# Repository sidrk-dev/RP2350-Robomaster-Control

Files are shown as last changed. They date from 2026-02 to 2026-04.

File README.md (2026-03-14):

# RoboMaster Motor Control (Pico + MCP2515)

Control up to 8 DJI RoboMaster motors (M3508/M2006) using a Raspberry Pi Pico and MCP2515 CAN Bus module. This project provides a serial command interface to control position, speed, PID tuning, calibration, and homing.

## Features

- **Position Control**: Move motors to absolute angles (0-360 degrees).
- **Speed Control**: Set continuous rotation speed (RPM).
- **PID Tuning**: Adjust Angle and Speed PID gains on the fly.
- **Calibration**: Set the current physical position to a specific angle.
- **Gear Ratios**: Configure external gear reductions.
- **Multi-Motor Support**: Control up to 8 motors on a single CAN bus.
- **Brushed DC Support**: Integrated support for Cytron MD10C motor drivers.
- **Configuration Management**: GUI utility to tune PID loops, set gear ratios, and save multi-motor parameters to JSON.
- **Inverse Kinematics UI**: Full 3D 6-DOF visualization and control panel for coordinate based movement.
- **Python Control Scripts**: Control the RoboMaster and Cytron motors directly from your laptop using keyboard inputs.

## Hardware Setup

### Components
- **Microcontroller**: Raspberry Pi Pico (RP2040)
- **CAN Controller**: MCP2515 Module (SPI)
- **Motors**: DJI RoboMaster M3508 or M2006 (with C620/C610 ESCs)
- **Power Supply**: 24V DC (for motors)

### Wiring (Pico <-> MCP2515)

| Pico Pin | MCP2515 Pin | Function |
| :--- | :--- | :--- |
| GPIO 4 | SO (MISO) | SPI RX |
| GPIO 5 | CS | Chip Select |
| GPIO 6 | SCK | SPI Clock |
| GPIO 7 | SI (MOSI) | SPI TX |
| VBUS/VSYS| VCC | 5V Power |
| GND | GND | Ground |

*Note: The MCP2515 INT pin is not currently used in this code.*

> **IMPORTANT**: The Raspberry Pi Pico, MCP2515, and the Motor Controller (ESC) power supply **MUST share a common ground**. Failing to connect the grounds will result in communication failure.

### CAN Bus Wiring
- Connect generic CAN High and CAN Low from the MCP2515 to the CAN High and CAN Low on the motor ESCs.
- Ensure the CAN bus is terminated with 120Ω resistors at both ends.
- **Motor IDs**: Set motor IDs (1-8) on the ESCs according to the DJI documentation (usually by pressing the button on the ESC).

### Cytron MD10C Wiring (Optional)
If you are using a standard brushed DC motor via the Cytron MD10C:
| Pico Pin | MD10C Pin | Function |
| :--- | :--- | :--- |
| GPIO 26  | PWM | Motor Speed |
| GPIO 27  | DIR | Motor Direction |
| GND | GND | Ground |

## Software Setup

### 1. Install Arduino IDE
Download and install the latest Arduino IDE from [arduino.cc](https://www.arduino.cc/en/software).

### 2. Install Raspberry Pi Pico Board Support
1. Open Arduino IDE.
2. Go to **File** > **Preferences**.
3. In "Additional Boards Manager URLs", add:
   `https://github.com/earlephilhower/arduino-pico/releases/download/global/package_rp2040_index.json`
4. Go to **Tools** > **Board** > **Boards Manager**.
5. Search for "Pico" and install **"Raspberry Pi Pico/RP2040" by Earle F. Philhower, III**.

### 3. Libraries
All required libraries are included in the `src` folder. No manual library installation is required.

- `autowp-mcp2515` (Modified for local include)
- `RPi_Pico_TimerInterrupt` (Modified for local include)

### 4. Upload Code
1. Open `goo.ino` in Arduino IDE.
2. Connect your Raspberry Pi Pico via USB while holding the BOOTSEL button (or just connect if already in flash mode/serial enabled).
3. Select your board: **Tools** > **Board** > **Raspberry Pi Pico**.
4. Select the Port: **Tools** > **Port**.
5. Click **Upload** (Right arrow icon).

## Code Configuration (Permanent Settings)

To change default settings permanently, edit `goo.ino`:

1.  **Pin Definitions**:
    ```cpp
    #define RX_PIN 4  // gpio4 (MISO)
    #define CS_PIN 5  // gpio5 (CS)
    #define SCK_PIN 6 // gpio6 (SCK)
    #define TX_PIN 7  // gpio7 (MOSI)
    ```
2.  **Motor Count**:
    ```cpp
    #define MOTOR_NUM 8 // Change if using fewer motors
    ```
3.  **Default Gear Ratios and PID**:
    Locate the `setMotorParam()` function.
    -   Modify `motor[i].gearRatio` for M3508 (approx 19.0) or M2006 (36.0).
    -   Modify default PID values in `motor[i].anglePid` and `motor[i].speedPid`.

## Usage (Serial Monitor)

Open the **Serial Monitor** (Tools > Serial Monitor) and set the baud rate to **115200**. Ensure "Both NL & CR" or "Newline" is selected.

### Basic Commands

| Command | Description | Example |
| :--- | :--- | :--- |
| `H` | Show Help menu | `H` |
| `S` | **STOP ALL MOTORS** | `S` |

### Motor Control

| Command | Description | Example |
| :--- | :--- | :--- |
| `P <id> <angle>` | Move Motor `<id>` to limits `<angle>` (0-360) | `P 1 90` (Motor 1 to 90°) |
| `M <id> <rpm>` | Run Motor `<id>` at speed `<rpm>` | `M 2 500` (Motor 2 at 500 RPM) |
| `CAL <id> <angle>` | Calibrate: Set current position to `<angle>` | `CAL 1 0` (Set current pos as 0°) |
| `GEAR <id> <ratio>` | Set external gear ratio | `GEAR 1 5` (5:1 reduction) |
| `C <speed>` | Run Cytron motor at speed `-255` to `255` | `C 127` (50% forward) |

### PID Tuning
Adjust the control loop behavior. Values are saved until restart.

| Command | Description | Example |
| :--- | :--- | :--- |
| `AP <id> <kp> <ki> <kd>` | Set **Angle** PID | `AP 1 10.0 0.0 0.5` |
| `SP <id> <kp> <ki> <kd>` | Set **Speed** PID | `SP 1 2.0 0.1 0.0` |
| `SHOW <id>` | Show current PID values | `SHOW 1` |

## Python Control Scripts

This repository includes Python scripts and graphical interfaces to allow you to control the motors directly from your laptop.
First, make sure to install dependencies:
```bash
pip install ikpy pyserial matplotlib numpy scipy pynput
```

- **`ik_dashboard_qt.py`** (**Primary / Main arm dashboard**): Recommended day-to-day control UI for IK + runtime operation (reconnect handling, verify flow, execute/live controls).
- **`pid_tuner.py`** (**Primary tuning tool**): Dedicated Tkinter GUI for motor parameter maintenance (PID, limits, ENCMAP/ABSPID, and config persistence).
- **`ik_arm_control.py`**: Backend + legacy visualizer internals used by the Qt dashboard.
- **`keyboard_control.py`**: Hold `W` to spin RoboMaster Motor 1 forward, `S` to spin backward. `Q` to quit.
- **`differential_wrist_control.py`**: Uses WASD to control a differential wrist attached to Motors 1 and 2. `W/S` for Pitch, `A/D` for Roll.
- **`cytron_control.py`**: Hold `U` to spin the Cytron motor forward (PWM 255), `J` to spin backward. `Q` to quit.
- **`multi_motor_keyboard_control.py`**: Multi-controller keyboard velocity tool that reads controller ports from `robot_config.json`, opens all configured COM ports, and routes per-motor `M <id> <rpm>` commands with remappable keys.

## Multi-Motor Keyboard Controller (`multi_motor_keyboard_control.py`)

### Purpose
- Connects to all controller ports defined under `controllers` in `robot_config.json`.
- Routes velocity commands to the correct board based on motor assignment.
- Lets you hold/release remappable keys to command motor RPM live.

### Run
```bash
python multi_motor_keyboard_control.py
```

Optional arguments:
```bash
python multi_motor_keyboard_control.py --config robot_config.json --keymap multi_motor_keymap.json --baud 115200
```

### On startup
- If keymap file does not exist, the script creates `multi_motor_keymap.json` with defaults.
- It verifies every configured controller port is present before opening.
- It prints full usage instructions and all runtime key bindings.

### Key behavior
- Press/hold mapped **forward** key -> sends positive RPM for that motor.
- Press/hold mapped **reverse** key -> sends negative RPM for that motor.
- Release key -> sends `M <id> 0` for that motor.
- **Stop-All** key sends `S` to all connected controllers.
- **Quit** key exits and sends stop before closing ports.

### Remapping keys
Edit `multi_motor_keymap.json` and restart the script.

Schema:
```json
{
  "quit": "esc",
  "stop_all": "space",
  "blink": "b",
  "motors": {
    "1": { "forward": "1", "reverse": "q", "speed": 50 },
    "2": { "forward": "2", "reverse": "w", "speed": 50 }
  }
}
```

## Recommended Daily Workflow (Important)

This project has a multi-controller serial architecture (`base`, `joint4`, `wrist`).
Most runtime issues are from startup order, stale telemetry, or encoder mapping/offset mistakes.

### 1) One app at a time
- Do **not** run `ik_dashboard_qt.py` and `pid_tuner.py` at the same time.
- Close one before connecting with the other, or USB ports will conflict.

### 2) Power and cable checks first
- Make sure all expected controller boards are powered and plugged in.
- If one board is unplugged, motion may remain blocked in IK for safety.

### 3) Apply settings before motion
- In PID Tuner, use **Apply ALL Settings to Arm** after loading/checking config.
- In IK Dashboard, after reconnect, click **Post-Reconnect Verify + Arm Motion** before Execute/Live.

### 4) Wait for telemetry
- Confirm live `POS` telemetry appears for joints before testing motion.
- If telemetry is stale/missing, IK motion will be blocked.

---

## IK Dashboard (`ik_dashboard_qt.py`) - How to Use

### Startup
1. Launch `python ik_dashboard_qt.py`
2. Click **Connect**.
3. Wait for connection + telemetry status to become healthy.
4. Click **Post-Reconnect Verify + Arm Motion**.
5. Use **Execute** for one-shot movement or **Live Update** for continuous updates.

### Safety/Behavior Notes
- The dashboard intentionally enforces runtime safety gates:
  - runtime apply must be confirmed,
  - required controllers must be online,
  - telemetry must be live,
  - motion must be armed after verify.
- If any of the above fails, Execute is blocked and a reason is logged.

### Joint 4 note
- If Joint 4 does not move from IK, check whether backend is in planar-lock mode.
- In planar mode, joint 4 can be intentionally locked out from IK command generation.

---

## PID Tuner (`pid_tuner.py`) - How to Use

### Typical sequence
1. Launch `python pid_tuner.py`
2. Connect to controllers.
3. Review motor config values loaded from `robot_config.json`.
4. Click **Apply Encoder Mappings** (or **Apply ALL Settings to Arm**).
5. Wait briefly for encoder detection settle.
6. Apply/enable ABS PID.
7. Test with small moves first (`P`/Jog), then larger movements.

### Encoder mapping and ABSPID sequencing quirk
- ABSPID enable can fail if sent too quickly after mapping.
- Correct order is:
  1. `ENCMAP`
  2. short wait for firmware detection
  3. `ABSPID`
- The tooling now retries ABSPID enables, but you should still wait for telemetry stability.

### Shared encoder index across boards
- Same encoder index value can be reused on different controller boards.
- Conflict only matters **within the same controller** (same board/firmware instance).

---

## Common Errors and Fixes

### 1) "Motion blocked" in IK Dashboard
**Symptoms**
- Execute does nothing
- Logs mention runtime apply/telemetry/controller health

**Fix**
1. Reconnect all boards.
2. Confirm telemetry is updating.
3. Run **Post-Reconnect Verify + Arm Motion**.
4. Retry Execute.

### 2) One controller unplugged / wrong COM port
**Symptoms**
- One joint group (often J4 or wrist) never responds.
- Status shows offline/missing controller.

**Fix**
1. Check USB cable and power for that board.
2. Confirm controller mapping in `robot_config.json` (`controllers.base/joint4/wrist.port`).
3. Reconnect app and verify again.

### 3) ABSPID skipped / not enabled
**Symptoms**
- Serial log includes `ABSPID skipped`.
- Motor stays on internal encoder PID source.

**Likely causes**
- No encoder mapped for that motor.
- Encoder not detected yet right after remap.

**Fix**
1. Set correct `abs_encoder_index` for that motor.
2. Apply encoder mappings.
3. Wait ~0.2-0.5s.
4. Enable ABSPID again (or use Apply ALL).

### 4) Motor moves opposite direction
**Symptoms**
- Position correction runs away or moves opposite expected command.

**Fix**
1. Flip `abs_encoder_reversed` for that motor.
2. Re-apply encoder mapping/direction.
3. Re-enable ABSPID and retest with tiny move.

### 5) Wrong zero / bad encoder offset
**Symptoms**
- Displayed pose is offset from real arm.
- Commanded target goes to unexpected physical angle.

**Fix**
1. Put arm in known reference pose.
2. Recalibrate with `CAL <id> <angle>` (or dashboard zero capture workflow).
3. Verify `abs_zero_offset` / `ik_zero_offset` in `robot_config.json` are correct.
4. Apply settings, then sync from telemetry before executing motion.

### 6) Jog spins continuously instead of stepping
**Symptoms**
- Jog behaves like continuous speed command.

**Fix**
- Use updated PID tuner jog path that sends bounded position targets (`P`) from current telemetry reference.
- Ensure live telemetry is present before jogging.

---

## Quick Command Reference (Firmware)

- `S` -> stop all motors
- `TON` / `TOFF` -> telemetry on/off
- `P <id> <angle>` -> absolute logical position target
- `PR <id> <delta>` -> relative logical position step
- `M <id> <rpm>` -> continuous speed command
- `ENCMAP <enc_idx> <motor_id|0>` -> map/unmap absolute encoder
- `ENCREVSET <enc_idx> <0|1> <motor_id>` -> deterministic encoder direction
- `ABSPID <id> <0|1>` -> toggle absolute-encoder PID source
- `CAL <id> <angle>` -> set logical zero reference at current physical position

## Documentation

For more detailed guides, see the included markdown files:
- [PID Tuning Guide](PID_TUNING_GUIDE.md)
- [Gear Ratio Guide](GEAR_RATIO_GUIDE.md)
- [Multi-Motor Reference](MULTI_MOTOR_REFERENCE.md)

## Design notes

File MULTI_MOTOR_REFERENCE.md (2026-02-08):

# Multi-Motor Control - Quick Reference

## All Motors Now Support Position Control!

All 8 motors now have the same PID tuning and can be controlled independently for position or speed.

## Command Format Changes

### Position Control
**Old (Motor 1 only):**
```
P 90
```

**New (All motors):**
```
P 1 90      # Motor 1 to 90 degrees
P 2 180     # Motor 2 to 180 degrees
P 3 270     # Motor 3 to 270 degrees
```

### Calibration
**Old (Motor 1 only):**
```
CAL 0
```

**New (All motors):**
```
CAL 1 0     # Set Motor 1 current position to 0°
CAL 2 90    # Set Motor 2 current position to 90°
CAL 3 180   # Set Motor 3 current position to 180°
```

### PID Tuning
**Old (Motor 1 only):**
```
AP 5 1.0 0.0
SP 0.3 0 0
SHOW
```

**New (All motors):**
```
AP 1 5 1.0 0.0    # Set Motor 1 angle PID
AP 2 5 1.0 0.0    # Set Motor 2 angle PID
SP 1 0.3 0 0      # Set Motor 1 speed PID
SP 2 0.3 0 0      # Set Motor 2 speed PID
SHOW 1            # Show Motor 1 PID values
SHOW 2            # Show Motor 2 PID values
```

### Speed Control (unchanged)
```
M 1 500     # Motor 1 at 500 RPM
M 2 -300    # Motor 2 at -300 RPM
```

## Complete Command List

| Command | Format | Example | Description |
|---|---|---|---|
| **P** | `P <id> <angle>` | `P 1 90` | Move motor to absolute angle (0-360°) |
| **M** | `M <id> <speed>` | `M 2 500` | Set motor to continuous speed (RPM) |
| **CAL** | `CAL <id> <angle>` | `CAL 1 0` | Calibrate current position to angle |
| **AP** | `AP <id> <kp> <ki> <kd>` | `AP 1 5 1 0` | Set angle PID for motor |
| **SP** | `SP <id> <kp> <ki> <kd>` | `SP 1 0.3 0 0` | Set speed PID for motor |
| **SHOW** | `SHOW <id>` | `SHOW 1` | Display PID values for motor |
| **S** | `S` | `S` | Stop ALL motors |
| **H** | `H` | `H` | Show help |

## Default PID Values (All Motors)

```
Angle PID: Kp=5.0, Ki=1.0, Kd=0.0, OutLimit=500 RPM, IntLimit=5.0
Speed PID: Kp=0.3, Ki=0.0, Kd=0.0, OutLimit=20 A, IntLimit=5.0
```

These are tuned for M3508 motors (19:1 gear ratio).

## Status Display

The serial monitor now shows status for ALL motors in position control mode:

```
M1 POS:90.2 Tot:90.2 RPM:0.5 A:0.12 | M3 POS:180.1 Tot:180.1 RPM:-1.2 A:0.08 |
```

- **POS** - Current position (0-360°)
- **Tot** - Total angle (can exceed 360°)
- **RPM** - Current speed
- **A** - Current in Amps

## Example Multi-Motor Workflow

### Setup Multiple Motors
```
S                   # Stop all
CAL 1 0             # Calibrate motor 1 to 0°
CAL 2 0             # Calibrate motor 2 to 0°
CAL 3 0             # Calibrate motor 3 to 0°
```

### Coordinated Movement
```
P 1 90              # Motor 1 to 90°
P 2 180             # Motor 2 to 180°
P 3 270             # Motor 3 to 270°
```

### Individual Tuning
```
SHOW 1              # Check Motor 1 PID
AP 1 7 1 0.1        # Increase Motor 1 responsiveness
SHOW 2              # Check Motor 2 PID
AP 2 3 0.5 0.2      # Make Motor 2 more damped
```

### Return to Zero
```
P 1 0
P 2 0
P 3 0
```

## LED Indicator

The built-in LED turns ON when **any** motor is in position control mode.

## Notes

- All motors share the same default PID values at startup
- You can tune each motor independently during runtime
- PID values reset to defaults on power cycle
- Position tracking works across multiple rotations
- Shortest path is automatically calculated for position commands

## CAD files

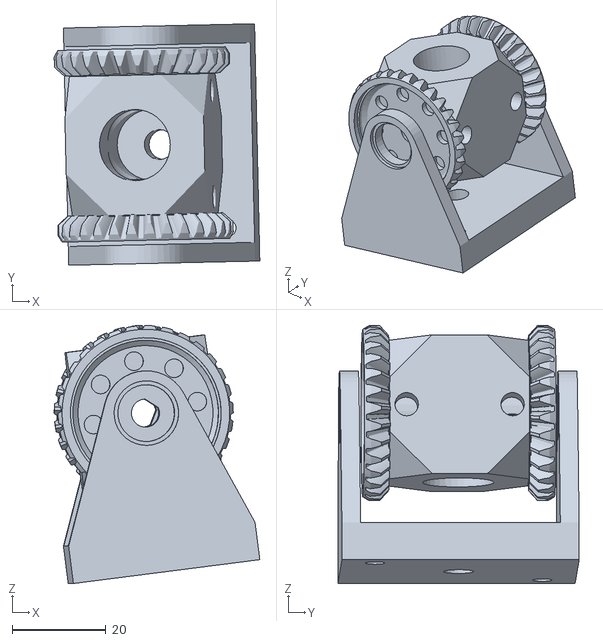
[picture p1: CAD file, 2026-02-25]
URDF/meshes/J5to6_v111.stl
43.8 x 51.4 x 54.9

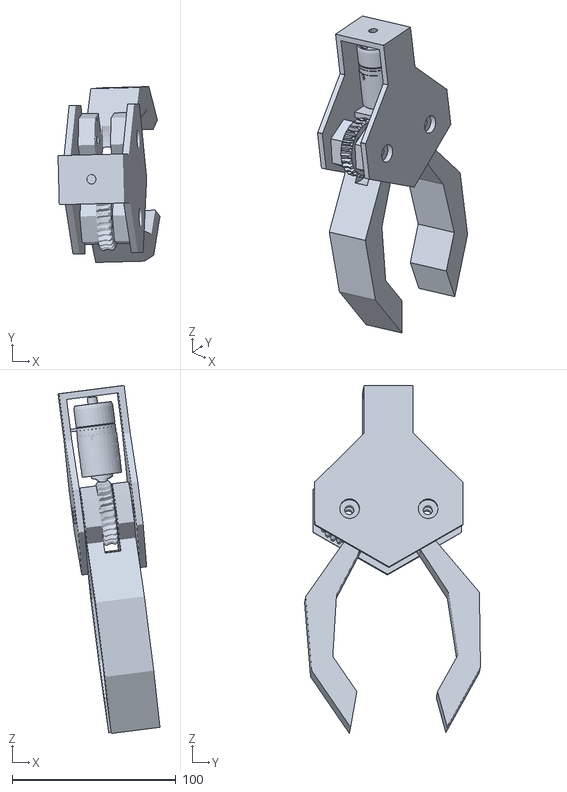
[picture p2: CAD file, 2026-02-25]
URDF/meshes/hand_v111.stl
62.3 x 107.5 x 212.7

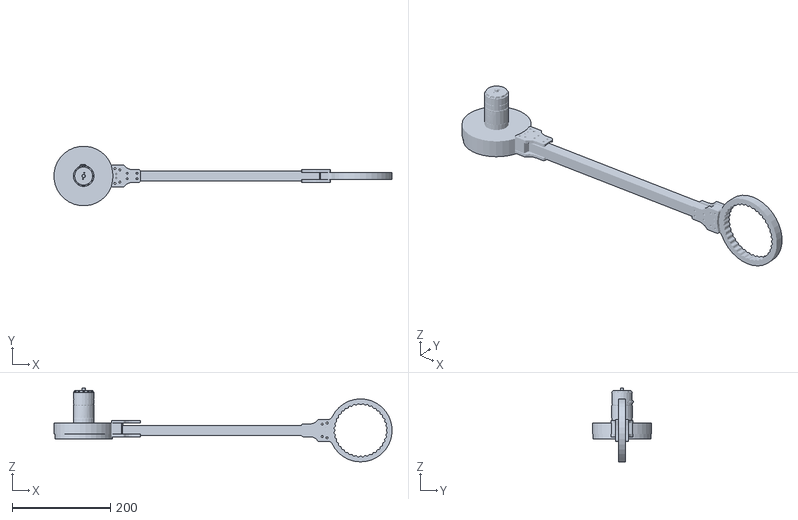
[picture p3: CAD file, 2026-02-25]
URDF/meshes/J3to4_v111.stl
686.4 x 120.7 x 149.8

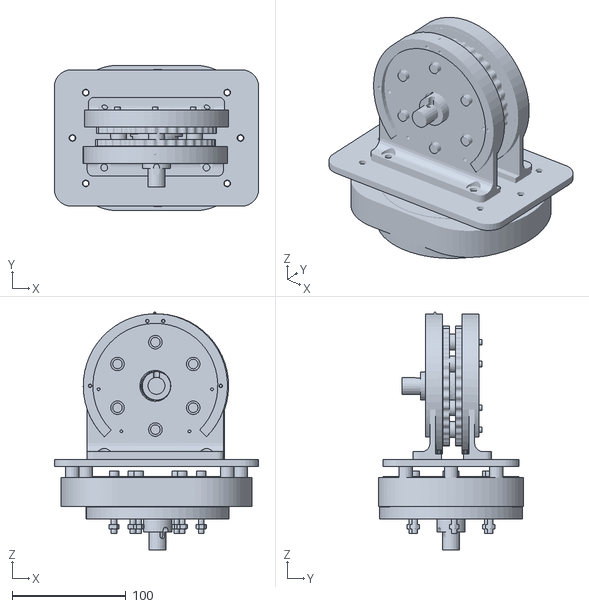
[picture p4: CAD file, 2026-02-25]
URDF/meshes/J1to2_v111.stl
180.0 x 128.0 x 209.5

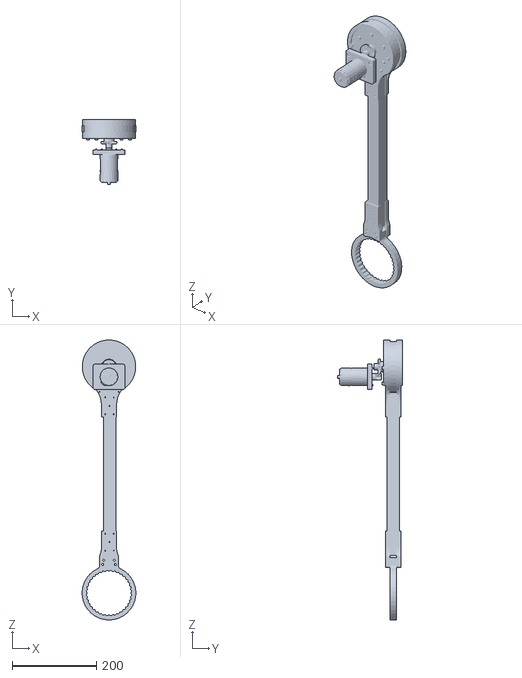
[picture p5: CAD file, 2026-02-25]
URDF/meshes/J2to3_v211.stl
127.8 x 155.1 x 665.5

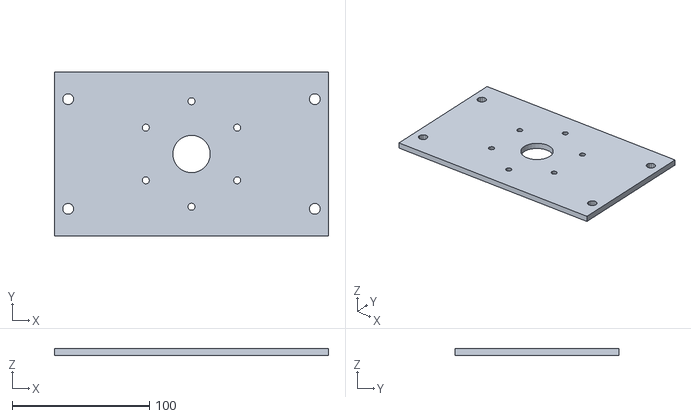
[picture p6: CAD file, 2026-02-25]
URDF/meshes/base_link.stl
200.0 x 120.0 x 5.00

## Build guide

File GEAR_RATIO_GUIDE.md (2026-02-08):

# External Gear Ratio & Calibration Fix

## What Changed

### 1. External Gear Ratio Support
Each motor can now have an **external gear ratio** in addition to its internal motor gear ratio. This is useful when you have:
- Belt/pulley reductions
- Additional gearboxes
- Chain drives
- Any external mechanical advantage

### 2. Calibration Fix
The calibration was failing because `externalGearRatio` wasn't initialized. It's now properly set to `1.0` (no external gearing) by default.

## New Command: GEAR

### Format
```
GEAR <id> <ratio>
```

### Examples
```
GEAR 1 5        # Motor 1 has 5:1 external gearing
GEAR 2 3.5      # Motor 2 has 3.5:1 external gearing
GEAR 3 1        # Motor 3 has no external gearing (default)
```

### How It Works

**Total Gear Ratio = Motor Internal Ratio × External Ratio**

For example:
- M3508 motor: 19:1 internal ratio
- External gearing: 5:1
- **Total ratio: 19 × 5 = 95:1**

This means:
- Position control works on the **final output shaft**
- Speed (RPM) is measured at the **final output**
- All calculations account for the total reduction

## Updated Workflow

### Setup with External Gearing

```bash
# 1. Set external gear ratios (if any)
GEAR 1 5        # Motor 1 has 5:1 external reduction
GEAR 2 5        # Motor 2 has 5:1 external reduction
GEAR 3 1        # Motor 3 has no external gearing

# 2. Calibrate positions
CAL 1 0         # Set Motor 1 current position to 0°
CAL 2 0         # Set Motor 2 current position to 0°
CAL 3 0         # Set Motor 3 current position to 0°

# 3. Move to positions (final output shaft degrees)
P 1 90          # Motor 1 final output to 90°
P 2 180         # Motor 2 final output to 180°
P 3 270         # Motor 3 final output to 270°
```

## Understanding the Gear Ratios

### Default Configuration (from your code)
```cpp
#define M2006_GEAR_RATIO 19.0 * 5  // = 95:1
```

This sets the **motor internal ratio** to 95:1. If you have additional external gearing, use the `GEAR` command to add it.

### Example Calculation

**Motor 1 with M3508 (19:1) + 5:1 external gearing:**

```bash
# Motor setup
motor[0].gearRatio = 95.0          # From M2006_GEAR_RATIO define
motor[0].externalGearRatio = 5.0   # Set via GEAR 1 5

# Total ratio
Total = 95.0 × 5.0 = 475:1

# If motor rotor spins 475 revolutions
# Final output shaft spins 1 revolution (360°)
```

## Calibration Now Works!

### Why It Was Broken
The `externalGearRatio` field wasn't initialized, so it had a random value (could be 0 or garbage). This caused:
- Division by zero errors
- Incorrect position calculations
- Calibration being immediately overwritten

### The Fix
```cpp
motor[i].externalGearRatio = 1.0;  // Default: no external gearing
```

Now calibration works correctly:
```bash
CAL 1 0      # Sets current position to 0°
P 1 90       # Moves to 90° (works!)
```

## Checking Your Setup

### View Total Gear Ratio
```bash
GEAR 1 5
# Output: Motor 1 external gear ratio set to 5:1 (Total ratio: 475:1)
```

### View PID Settings
```bash
SHOW 1
# Shows all PID values and limits
```

## Important Notes

### 1. Set Gear Ratio BEFORE Calibration
```bash
# CORRECT ORDER:
GEAR 1 5        # Set gear ratio first
CAL 1 0         # Then calibrate

# WRONG ORDER:
CAL 1 0         # Calibrate first
GEAR 1 5        # Changing ratio invalidates calibration!
```

### 2. Gear Ratio Affects Speed
If you set `GEAR 1 5`, the reported RPM will be 5× slower (final output speed).

### 3. Gear Ratio Affects Position
With higher gear ratios, you get:
- **More precision** (smaller motor movements = smaller output movements)
- **More torque** at the output
- **Slower maximum speed** at the output

## PID Tuning with External Gearing

Higher gear ratios may require different PID values:

```bash
# With 5:1 external gearing, you might need:
AP 1 10 1 0.2    # Higher Kp for faster response
SP 1 0.5 0 0     # Higher speed Kp
```

The position error is in **output shaft degrees**, which are smaller movements with high gear ratios.

## Complete Example Session

```bash
# Setup
H                # Show help
S                # Stop all motors

# Configure gear ratios
GEAR 1 5         # Motor 1: 5:1 external
GEAR 2 5         # Motor 2: 5:1 external  
GEAR 3 1         # Motor 3: no external gearing

# Calibrate
CAL 1 0          # Motor 1 at 0°
CAL 2 0          # Motor 2 at 0°
CAL 3 0          # Motor 3 at 0°

# Test movement
P 1 90           # Motor 1 to 90°
P 2 180          # Motor 2 to 180°
P 3 270          # Motor 3 to 270°

# Check status (shows final output positions)
# M1 POS:90.1 Tot:90.1 RPM:0.2 A:0.05 | M2 POS:180.0 ...

# Return home
P 1 0
P 2 0
P 3 0
```

## Troubleshooting

### Calibration Still Not Working?
1. Check that you set `GEAR` before `CAL`
2. Verify gear ratio is positive: `GEAR 1 5` (not 0 or negative)
3. Make sure motor is stopped before calibrating: `S` then `CAL 1 0`

### Position Drifts After Calibration?
- This is normal if the motor is moving
- Calibration sets the position at that instant
- Movement continues from the new reference

### Wrong Speed/Position Readings?
- Check your `M2006_GEAR_RATIO` define
- Verify external gear ratio is correct
- Total ratio = internal × external

## Summary

✅ **External gear ratios** now supported via `GEAR` command  
✅ **Calibration fixed** by initializing `externalGearRatio = 1.0`  
✅ **All calculations** use total gear ratio (internal × external)  
✅ **Position and speed** measured at final output shaft  

The lint errors are just IDE warnings - the code will compile fine in Arduino IDE!

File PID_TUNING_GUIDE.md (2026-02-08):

# PID Tuning Guide for RoboMaster Motor Position Control

## Overview
Your system uses **cascade PID control**:
- **Outer Loop (Position)**: Angle PID converts position error (degrees) → target speed (RPM)
- **Inner Loop (Speed)**: Speed PID converts speed error (RPM) → motor current (Amps)

## Current Problem: Motor Vibrating
This typically means the system is **over-responsive** or **oscillating**. Common causes:
1. **Kp too high** - System reacts too aggressively
2. **Kd too low** - Not enough damping
3. **Ki causing windup** - Integral term accumulating too much

## Quick Fix Commands

### View Current Settings
```
SHOW
```

### Emergency Stop
```
S
```

### Test Position Control
```
P 90
```

## Step-by-Step Tuning Process

### Phase 1: Stabilize Speed Loop First
The speed loop must be stable before tuning position control.

**Start with conservative values:**
```
SP 0.5 0 0
```

**Test with direct speed command:**
```
M 1 100
```

**Gradually increase Kp until you get good tracking:**
```
SP 1.0 0 0
SP 2.0 0 0
SP 3.0 0 0
```

**Signs of good speed control:**
- Motor reaches target RPM smoothly
- No oscillation or vibration
- Steady-state error is acceptable

**If oscillating:** Lower Kp
```
SP 0.5 0 0
```

**If sluggish:** Add a tiny bit of Ki (start very small!)
```
SP 2.0 0.1 0
```

**If noisy/jittery:** Add Kd for damping
```
SP 2.0 0.1 0.05
```

### Phase 2: Tune Position Loop
Once speed control is stable, tune the position loop.

**Start with very low Kp:**
```
AP 0.1 0 0
```

**Test position control:**
```
P 90
```

**Gradually increase Kp:**
```
AP 0.3 0 0
AP 0.5 0 0
AP 1.0 0 0
```

**Signs of good position control:**
- Motor moves smoothly to target
- Settles without overshoot
- No vibration at target position

**If vibrating at target:** Add Kd for damping
```
AP 0.5 0 0.2
AP 0.5 0 0.5
```

**If slow to reach target:** Increase Kp
```
AP 1.5 0 0.5
```

**If steady-state error (doesn't quite reach target):** Add tiny Ki
```
AP 1.0 0.05 0.5
```

## Recommended Starting Values

### For M2006 Motors (36:1 gear ratio)
```
SP 1.0 0.1 0      # Speed PID
AP 0.5 0 0.3      # Angle PID
```

### For M3508 Motors (19:1 gear ratio)
```
SP 2.0 0.2 0      # Speed PID
AP 1.0 0 0.5      # Angle PID
```

## Understanding the Parameters

### Kp (Proportional Gain)
- **What it does:** Immediate response to error
- **Too high:** Oscillation, vibration, overshoot
- **Too low:** Slow response, large steady-state error
- **Typical range:** 0.1 - 5.0

### Ki (Integral Gain)
- **What it does:** Eliminates steady-state error over time
- **Too high:** Overshoot, slow settling, instability
- **Too low:** Persistent steady-state error
- **Typical range:** 0 - 0.5 (start with 0!)
- **⚠️ Warning:** Can cause windup - use sparingly

### Kd (Derivative Gain)
- **What it does:** Damping, resists rapid changes
- **Too high:** Amplifies noise, jittery motion
- **Too low:** Overshoot, oscillation
- **Typical range:** 0 - 1.0

## Troubleshooting Guide

### Problem: Motor vibrates/oscillates at target position
**Cause:** Position loop Kp too high or Kd too low
**Fix:**
```
AP 0.3 0 0.5    # Lower Kp, add damping
```

### Problem: Motor overshoots target
**Cause:** Not enough damping
**Fix:**
```
AP 0.5 0 1.0    # Increase Kd
```

### Problem: Motor doesn't reach exact target
**Cause:** Steady-state error, need integral term
**Fix:**
```
AP 1.0 0.05 0.5  # Add small Ki
```

### Problem: Motor moves very slowly
**Cause:** Position Kp too low or speed limit too low
**Fix:**
```
AP 2.0 0 0.5    # Increase Kp
```
Or check that `outputLimit` (max RPM) is reasonable (default: 500 RPM)

### Problem: Motor makes grinding noise
**Cause:** Speed loop too aggressive or current limit too high
**Fix:**
```
SP 0.5 0 0      # Lower speed Kp
```

### Problem: Erratic behavior after running for a while
**Cause:** Integral windup
**Fix:**
```
AP 1.0 0 0.5    # Remove Ki from angle PID
SP 2.0 0 0      # Remove Ki from speed PID
```

## Advanced: Understanding Limits

### Output Limits
- **Angle PID outputLimit:** Maximum RPM command (default: 500)
  - Higher = faster motion
  - Lower = smoother, safer motion
  
- **Speed PID outputLimit:** Maximum current in Amps (default: 20)
  - M2006: Max ~10A continuous, 20A peak
  - M3508: Max ~20A continuous

### Integral Limits
- **integralLimit:** Maximum integral accumulation (default: 5.0)
  - Prevents integral windup
  - Should be ~25% of outputLimit

## Tuning Workflow Summary

1. **Stop everything:** `S`
2. **Check current values:** `SHOW`
3. **Start conservative:** `SP 0.5 0 0` and `AP 0.1 0 0`
4. **Test speed first:** `M 1 100`
5. **Tune speed loop** until stable
6. **Test position:** `P 90`
7. **Tune position loop** incrementally
8. **Add damping (Kd)** if oscillating
9. **Add integral (Ki)** only if needed for steady-state error
10. **Document your final values!**

## Example Tuning Session

```
# Start fresh
S
SHOW

# Conservative speed control
SP 0.5 0 0
M 1 100
# (observe - is it smooth?)

# Increase responsiveness
SP 1.0 0 0
M 1 100
# (better tracking?)

# Add tiny integral for steady-state
SP 1.0 0.1 0
M 1 100
# (reaches target exactly?)

# Now tune position - start low
AP 0.3 0 0
P 90
# (moves but slow?)

# Increase position gain
AP 0.8 0 0
P 180
# (faster but oscillates?)

# Add damping
AP 0.8 0 0.5
P 270
# (smooth and stable!)

# Final check
SHOW
# Document these values!
```

## Tips for Success

1. **Change ONE parameter at a time**
2. **Make small incremental changes** (0.1 - 0.5 steps)
3. **Wait for system to settle** before next change
4. **Start with Kp only**, add Kd second, Ki last
5. **Speed loop MUST be stable** before tuning position
6. **Lower values are safer** - start conservative
7. **Test multiple target positions** (0°, 90°, 180°, 270°)
8. **Watch the serial output** for actual values
9. **Document your final working values!**

## Safety Notes

- Always have `S` (stop) command ready
- Start with low gains to avoid damage
- Monitor motor temperature (shown in status)
- If motor gets hot (>60°C), reduce gains
- Current limit protects motor - don't exceed 20A for long periods

## Your Current Settings (from code)

```
Angle PID: Kp=1.0, Ki=0.0, Kd=0.5, OutLimit=500, IntLimit=5.0
Speed PID: Kp=1.0, Ki=0.5, Kd=0.0, OutLimit=20, IntLimit=5.0
```

**Recommendation for vibration issue:**
Try these more conservative values:
```
SP 0.5 0 0      # Lower speed Kp, remove Ki
AP 0.3 0 0.5    # Lower position Kp, keep damping
```

Then gradually increase from there!

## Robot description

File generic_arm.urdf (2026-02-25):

<?xml version="1.0"?>
<robot name="generic_6dof_arm">
  <!-- Base Link -->
  <link name="base_link">
    <visual>
      <geometry>
        <cylinder length="0.1" radius="0.1"/>
      </geometry>
      <material name="blue">
        <color rgba="0 0 1 1"/>
      </material>
    </visual>
  </link>

  <!-- Joint 1: Base rotation (Pan) -->
  <joint name="joint1" type="revolute">
    <parent link="base_link"/>
    <child link="link1"/>
    <origin xyz="0 0 0.05" rpy="0 0 0"/>
    <axis xyz="0 0 1"/>
    <limit lower="-3.14159" upper="3.14159" effort="10.0" velocity="1.0"/>
  </joint>

  <link name="link1">
    <visual>
      <geometry>
        <cylinder length="0.1" radius="0.05"/>
      </geometry>
      <material name="green">
        <color rgba="0 1 0 1"/>
      </material>
    </visual>
  </link>

  <!-- Joint 2: Shoulder (Tilt) -->
  <joint name="joint2" type="revolute">
    <parent link="link1"/>
    <child link="link2"/>
    <origin xyz="0 0 0.05" rpy="0 0 0"/>
    <axis xyz="0 1 0"/>
    <limit lower="-3.14159" upper="3.14159" effort="10.0" velocity="1.0"/>
  </joint>

  <link name="link2">
    <visual>
      <origin xyz="0 0 0.15" rpy="0 0 0"/>
      <geometry>
        <cylinder length="0.3" radius="0.04"/>
      </geometry>
      <material name="red">
        <color rgba="1 0 0 1"/>
      </material>
    </visual>
  </link>

  <!-- Joint 3: Elbow (Tilt) -->
  <joint name="joint3" type="revolute">
    <parent link="link2"/>
    <child link="link3"/>
    <origin xyz="0 0 0.3" rpy="0 0 0"/>
    <axis xyz="0 1 0"/>
    <limit lower="-3.14159" upper="3.14159" effort="10.0" velocity="1.0"/>
  </joint>

  <link name="link3">
    <visual>
      <origin xyz="0 0 0.15" rpy="0 0 0"/>
      <geometry>
        <cylinder length="0.3" radius="0.03"/>
      </geometry>
      <material name="yellow">
        <color rgba="1 1 0 1"/>
      </material>
    </visual>
  </link>

  <!-- Joint 4: Wrist 1 (Roll) -->
  <joint name="joint4" type="revolute">
    <parent link="link3"/>
    <child link="link4"/>
    <origin xyz="0 0 0.3" rpy="0 0 0"/>
    <axis xyz="0 0 1"/>
    <limit lower="-3.14159" upper="3.14159" effort="10.0" velocity="1.0"/>
  </joint>

  <link name="link4">
    <visual>
      <origin xyz="0 0 0.05" rpy="0 0 0"/>
      <geometry>
        <cylinder length="0.1" radius="0.025"/>
      </geometry>
      <material name="cyan">
        <color rgba="0 1 1 1"/>
      </material>
    </visual>
  </link>

  <!-- Joint 5: Wrist 2 (Tilt) -->
  <joint name="joint5" type="revolute">
    <parent link="link4"/>
    <child link="link5"/>
    <origin xyz="0 0 0.1" rpy="0 0 0"/>
    <axis xyz="0 1 0"/>
    <limit lower="-3.14159" upper="3.14159" effort="10.0" velocity="1.0"/>
  </joint>

  <link name="link5">
    <visual>
      <origin xyz="0 0 0.05" rpy="0 0 0"/>
      <geometry>
        <cylinder length="0.1" radius="0.02"/>
      </geometry>
      <material name="magenta">
        <color rgba="1 0 1 1"/>
      </material>
    </visual>
  </link>

  <!-- Joint 6: Wrist 3 (Roll) -->
  <joint name="joint6" type="revolute">
    <parent link="link5"/>
    <child link="hand"/>
    <origin xyz="0 0 0.1" rpy="0 0 0"/>
    <axis xyz="0 0 1"/>
    <limit lower="-3.14159" upper="3.14159" effort="10.0" velocity="1.0"/>
  </joint>

  <link name="hand">
    <visual>
      <origin xyz="0 0 0.05" rpy="0 0 0"/>
      <geometry>
        <cylinder length="0.1" radius="0.015"/>
      </geometry>
      <material name="grey">
        <color rgba="0.5 0.5 0.5 1"/>
      </material>
    </visual>
  </link>

</robot>

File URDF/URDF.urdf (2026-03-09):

<?xml version="1.0" ?>
<robot name="URDF">

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

<link name="base_link">
  <inertial>
    <origin xyz="4.134574372160573e-14 -1.9697829309959846e-17 -0.0025" rpy="0 0 0"/>
    <mass value="0.9061320027414785"/>
    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
  </inertial>
  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
</link>

<link name="hand_v111">
  <inertial>
    <origin xyz="0.013399974863583353 0.0014673587274294318 -0.10494199895736095" rpy="0 0 0"/>
    <mass value="1.5734552063055838"/>
    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
  </inertial>
  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
</link>

<link name="J5to6_v111">
  <inertial>
    <origin xyz="0.0014998156879051372 4.651259435907982e-05 -0.012405591131645632" rpy="0 0 0"/>
    <mass value="0.35001351454511986"/>
    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
  </inertial>
  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
</link>

<link name="J4to5_v111">
  <inertial>
    <origin xyz="6.804744117183681e-06 0.0005227247602343128 -0.029392065957235425" rpy="0 0 0"/>
    <mass value="4.55070610869959"/>
    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
  </inertial>
  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
</link>

<link name="J3to4_v111">
  <inertial>
    <origin xyz="-0.4157580723258036 -1.528505906127852e-05 0.006491989161569012" rpy="0 0 0"/>
    <mass value="5.095305748645674"/>
    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
  </inertial>
  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
</link>

<link name="J2to3_v211">
  <inertial>
    <origin xyz="0.0002441964978063141 -0.012514943272552637 0.42977520138921277" rpy="0 0 0"/>
    <mass value="6.769699046992388"/>
    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
  </inertial>
  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
</link>

<link name="J1to2_v111">
  <inertial>
    <origin xyz="-0.0009792145863911212 0.0003228728553376847 0.05805748683050891" rpy="0 0 0"/>
    <mass value="8.776151756630489"/>
    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
  </inertial>
  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
</link>

<joint name="Revolute_1" type="continuous">
  <origin xyz="0.004313 9.5e-05 -0.033725" rpy="0 0 0"/>
  <parent link="J5to6_v111"/>
  <child link="hand_v111"/>
  <axis xyz="0.126869 0.002806 -0.991916"/>
</joint>
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

<joint name="Revolute_2" type="continuous">
  <origin xyz="-0.001102 -2.4e-05 -0.09414" rpy="0 0 0"/>
  <parent link="J4to5_v111"/>
  <child link="J5to6_v111"/>
  <axis xyz="0.022114 -0.999755 0.0"/>
</joint>
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

<joint name="Revolute_3" type="continuous">
  <origin xyz="0.562444 0.0 -0.0175" rpy="0 0 0"/>
  <parent link="J3to4_v111"/>
  <child link="J4to5_v111"/>
  <axis xyz="0.0 0.0 1.0"/>
</joint>
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

<joint name="Revolute_4" type="continuous">
  <origin xyz="0.0 0.0 0.538" rpy="0 0 0"/>
  <parent link="J2to3_v211"/>
  <child link="J3to4_v111"/>
  <axis xyz="0.0 1.0 -0.0"/>
</joint>
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

<joint name="Revolute_5" type="continuous">
  <origin xyz="-0.001 0.00115 0.117" rpy="0 0 0"/>
  <parent link="J1to2_v111"/>
  <child link="J2to3_v211"/>
  <axis xyz="-0.0 1.0 -0.0"/>
</joint>
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

<joint name="Revolute_6" type="continuous">
  <origin xyz="0.0 0.0 0.0" rpy="0 0 0"/>
  <parent link="base_link"/>
  <child link="J1to2_v111"/>
  <axis xyz="0.0 0.0 1.0"/>
</joint>
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

</robot>

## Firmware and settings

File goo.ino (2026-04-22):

#include "motorControl.h"
#include "src/RPI_PICO_TimerInterrupt/src/RPi_Pico_TimerInterrupt.h"
#include "src/autowp-mcp2515/mcp2515.h"
#include <SPI.h>
#include <regex>

// Joints 1, 2, 3 Gear ratio is 94.23076923076923
// 10:1 gear ratio for the differential wrist

// -------------------- CONFIGURATION --------------------

/*#define RX_PIN 4  // D9  / GPIO4 (SPI0_MISO)
#define CS_PIN 1  // D7  / GPIO1 (SPI0_CSn)
#define SCK_PIN 2 // D8  / GPIO2 (SPI0_SCK)
#define TX_PIN 3  // D10 / GPIO3 (SPI0_MOSI)*/
#define HAND_DIR_PIN D5
#define HAND_PWM_PIN D6

// new test to switch to mobility code
#define RX_PIN D9  // D9  / GPIO4 (SPI0_MISO)
#define CS_PIN D3  // D7  / GPIO1 (SPI0_CSn)
#define SCK_PIN D8 // D8  / GPIO2 (SPI0_SCK)
#define TX_PIN D10 // D10 / GPIO3 (SPI0_MOSI)

// -------------------- ABSOLUTE ENCODER (AMT203S on SPI1) --------------------
#define ENC_SCK_PIN D0  // GPIO26 -> SPI1 SCK
#define ENC_MOSI_PIN D1 // GPIO27 -> SPI1 MOSI
#define ENC_MISO_PIN D2 // GPIO28 -> SPI1 MISO

#define ENC_NOP 0x00
#define ENC_RD_POS 0x10
#define ENC_SET_ZERO 0x70
#define ENC_TIMEOUT 100

const uint8_t ENC_CS_PINS[] = {D4};
const uint8_t NUM_ENCODERS = sizeof(ENC_CS_PINS) / sizeof(ENC_CS_PINS[0]);

#define M2006_GEAR_RATIO 36.0
#define M3508_GEAR_RATIO 19.0

// Supports IDs 1 through 8
#define MOTOR_NUM 8

#define DT_RECV_DATA 1.0f / (MOTOR_NUM * C620_FEEDBACK_125HZ)
#define DT_SEND_DATA 1.0f / C620_FEEDBACK_125HZ

// -------------------- OBJECTS --------------------
MCP2515 mcp(CS_PIN, 8000000, &SPI);
motorControl mc;
RPI_PICO_Timer recvTimer(0);
RPI_PICO_Timer sendTimer(1);

// -------------------- STATE MANAGEMENT --------------------
motor_t motor[MOTOR_NUM];
pidInterval_t pidInterval = {8, 4, 2};
bool motorTelemetryEnabled[MOTOR_NUM] =
    {}; // per-motor telemetry toggle (T command)

// Per-joint logical limits (degrees). Enforced in P and PR commands.
// Defaults: 0 to 360 (full rotation). Set via JLIM command.
float jointMin[MOTOR_NUM];
float jointMax[MOTOR_NUM];

// Per-joint wrapped physical offset (degrees, 0-360) used only for
// diagnostics/telemetry after CAL. Closed-loop control uses zeroAtControlTotal.
float zeroAtPhysical[MOTOR_NUM];

// Per-joint logical zero in the same total-angle frame used by PID.
// logicalAngle = controlTotalAngle - zeroAtControlTotal.
float zeroAtControlTotal[MOTOR_NUM];

// Open-loop velocity feedforward gain (A per RPM), used by MV command.
float mvGainAperRpm[MOTOR_NUM];

// Encoder-to-motor mapping: absEncoderMotorMap[enc_idx] = motor_idx (0-based),
// -1 = unmapped
int8_t absEncoderMotorMap[8]; // supports up to 8 encoders
bool encoderDetected[8];      // tracks which encoders responded to SPI
uint8_t encoderRetryCount[8]; // retry counter for failed encoders
bool absEncoderReversed[8];   // true if encoder reads opposite from motor

struct {
  bool recvMotor = false;
  bool sendMotor = false;
} flag;

struct can_frame sendMsg[2] = {};
struct can_frame readMsg = {};
int handPwmCommand = 0;
uint32_t blinkActiveUntilMs = 0;
uint32_t blinkLastToggleMs = 0;
bool blinkLedState = false;

// -------------------- PROTOTYPES --------------------
void SPIinit();
void SPI1init();
void MCPinit();
void setMotorParam();
void recvMotor();
void sendMotor();
bool recvMotorFlag(struct repeating_timer *t);
bool sendMotorFlag(struct repeating_timer *t);
void printHelp();
void handleSerial();
void processCommand(String line);
int16_t readAbsEncoder(uint8_t encoderIndex);
uint8_t SPIWriteToEncoder(uint8_t encoderIndex, uint8_t sendByte);
void updateAbsEncoders();
void startBlinkLed();
static float getControlTotalAngle(uint8_t motorIndex);
static float getControlLogicalAngle(uint8_t motorIndex);
static bool isJointFullRange(uint8_t motorIndex);
static int8_t findMappedEncoderForMotor(uint8_t motorIndex);
static float projectLogicalTargetToLimits(uint8_t motorIndex, float targetDeg,
                                          float referenceDeg);
static void clampActiveAngleTargetToLimits(uint8_t motorIndex);
static void fallbackMotorToInternalEncoder(uint8_t motorIndex);
static void resetAbsStateForMotor(uint8_t motorIndex);
void setHandPwm(int pwmCommand);

// -------------------- SETUP --------------------
void setup() {
  Serial.begin(115200);
  delay(1000);
  pinMode(LED_BUILTIN, OUTPUT);
  digitalWrite(LED_BUILTIN, LOW);

  SPIinit();
  SPI1init();
  MCPinit();
  setMotorParam();

  // Initialize joint limits to full range and zero offsets
  for (int i = 0; i < MOTOR_NUM; i++) {
    jointMin[i] = 0.0f;
    jointMax[i] = 360.0f;
    zeroAtPhysical[i] = 0.0f; // no offset by default
    zeroAtControlTotal[i] = 0.0f;
    mvGainAperRpm[i] = 0.02f; // default open-loop map: 100 RPM -> 2.0 A
  }

  // Default encoder-to-motor mapping: encoder 0 -> motor 0, encoder 1 -> motor
  // 1, etc.
  for (uint8_t i = 0; i < 8; i++) {
    absEncoderMotorMap[i] = (i < NUM_ENCODERS) ? (int8_t)i : -1;
    encoderDetected[i] = false;
    encoderRetryCount[i] = 0;
    absEncoderReversed[i] =
        true; // default: reversed (gearbox output reads opposite)
  }

  mc.setMotor(motor, MOTOR_NUM);
  mc.setPidInterval(&pidInterval);
  mc.init();

  // Use motor internal encoder for closed-loop control by default.
  // Absolute encoders remain available for APOS telemetry/debug.
  for (int i = 0; i < MOTOR_NUM; i++) {
    motor[i].useAbsEncoderForPID = false;
  }

  // Don't mark hasAbsEncoder=true yet - set on first successful SPI read

  // Timer interrupts
  recvTimer.attachInterruptInterval((uint32_t)(DT_RECV_DATA * 1000000),
                                    recvMotorFlag);
  sendTimer.attachInterruptInterval((uint32_t)(DT_SEND_DATA * 1000000),
                                    sendMotorFlag);

  // Prepare CAN frames (0x200 for IDs 1-4, 0x1FF for IDs 5-8)
  sendMsg[0].can_id = 0x200;
  sendMsg[0].can_dlc = 8;
  sendMsg[1].can_id = 0x1FF;
  sendMsg[1].can_dlc = 8;

  pinMode(LED_BUILTIN, OUTPUT);
  pinMode(HAND_DIR_PIN, OUTPUT);
  pinMode(HAND_PWM_PIN, OUTPUT);
  analogWrite(HAND_PWM_PIN, 0);
  digitalWrite(HAND_DIR_PIN, LOW);

  printHelp();
}

// -------------------- LOOP --------------------
void loop() {
  handleSerial();

  // Read absolute encoders (~100Hz, time-gated)
  static uint32_t lastEncRead = 0;
  if (millis() - lastEncRead > 10) {
    updateAbsEncoders();
    lastEncRead = millis();
  }

  // Status Printer: prints any motor with telemetry enabled (via T command) or
  // in ANGLE mode
  static uint32_t lastPrint = 0;
  if (millis() - lastPrint > 200) {
    bool anyPrinted = false;
    for (int i = 0; i < MOTOR_NUM; i++) {
      if (motor[i].mode == MODE::ANGLE || motorTelemetryEnabled[i]) {
        anyPrinted = true;

        // Choose control angle source used by closed-loop logic.
        float reportAngle = getControlTotalAngle(i);
        float logicalNow = getControlLogicalAngle(i);
        float rangeWidth = jointMax[i] - jointMin[i];
        float logicalDisplay =
            (rangeWidth >= 359.5f) ? wrap360f(logicalNow) : logicalNow;

        float physMod = fmod(reportAngle, 360.0f);
        if (physMod < 0)
          physMod += 360.0f;

        Serial.print("M");
        Serial.print(i + 1);
        Serial.print(" POS:"); // logical degrees (matches P command)
        Serial.print(logicalDisplay, 1);
        Serial.print(" PHYS:"); // raw physical reading
        Serial.print(physMod, 1);
        if (motor[i].hasAbsEncoder) {
          Serial.print(" APOS:"); // absolute encoder single-rev reading
          Serial.print(motor[i].absEncoderAngle, 1);
        }
        Serial.print(" Tot:");
        Serial.print(reportAngle, 1);
        Serial.print(" RPM:");
        Serial.print(motor[i].actualSpeed, 1);
        Serial.print(" A:");
        Serial.print(motor[i].actualCurrent, 2);
        Serial.print(" | ");
      }
    }
    if (anyPrinted)
      Serial.println();
    lastPrint = millis();
  }

  // CAN Communication
  if (flag.recvMotor)
    recvMotor();
  if (flag.sendMotor)
    sendMotor();

  // Status LED: ON if any motor is in angle mode
  bool anyAngleMode = false;
  for (int i = 0; i < MOTOR_NUM; i++) {
    if (motor[i].mode == MODE::ANGLE)
      anyAngleMode = true;
  }
  uint32_t nowMs = millis();
  if (blinkActiveUntilMs > nowMs) {
    if ((nowMs - blinkLastToggleMs) >= 200) {
      blinkLastToggleMs = nowMs;
      blinkLedState = !blinkLedState;
      digitalWrite(LED_BUILTIN, blinkLedState ? HIGH : LOW);
    }
  } else {
    blinkActiveUntilMs = 0;
    blinkLedState = false;
    digitalWrite(LED_BUILTIN, anyAngleMode ? HIGH : LOW);
  }
}

// -------------------- SERIAL COMMANDS --------------------
void printHelp() {
  Serial.println("\n=== RoboMaster Motor Control ===");
  Serial.println("  Use * as <id> to target ALL motors.  Separate cmds with ; "
                 "for batching.");
  Serial.println("");
  Serial.println("Position Control:");
  Serial.println("  P <id> <angle>    : Move to absolute logical angle");
  Serial.println(
      "  PR <id> <delta>   : Move RELATIVE delta degrees from current");
  Serial.println("  Example: P 1 90 | P * 0 | PR 2 -45");
  Serial.println("");
  Serial.println("Speed Control:");
  Serial.println("  M <id> <speed>    : Set speed in RPM (continuous)");
  Serial.println("  MV <id> <speed>   : Open-loop velocity (bypass Speed PID)");
  Serial.println("  MVG <id> <gain>   : Set MV gain (A per RPM)");
  Serial.println("  Example: M 1 500 | M * -300");
  Serial.println("");
  Serial.println("PID Tuning (full):");
  Serial.println("  AP <id> <kp> <ki> <kd> : Set all Angle PID gains");
  Serial.println("  SP <id> <kp> <ki> <kd> : Set all Speed PID gains");
  Serial.println("PID Tuning (single gain):");
  Serial.println("  KP  <id> <val>    : Angle Kp only");
  Serial.println("  KI  <id> <val>    : Angle Ki only");
  Serial.println("  KD  <id> <val>    : Angle Kd only");
  Serial.println("  AOL <id> <val>    : Angle output limit (max RPM)");
  Serial.println("  SKP <id> <val>    : Speed Kp only");
  Serial.println("  SKI <id> <val>    : Speed Ki only");
  Serial.println("  SKD <id> <val>    : Speed Kd only");
  Serial.println("  SOL <id> <val>    : Speed output limit (max Amps)");
  Serial.println("  SHOW <id>         : Show PID values");
  Serial.println("");
  Serial.println("Telemetry:");
  Serial.println("  T             : Toggle telemetry for ALL motors");
  Serial.println("  T <id>        : Toggle telemetry for one motor");
  Serial.println("");
  Serial.println("Calibration:");
  Serial.println("  CAL <id> <angle>  : Set current position to <angle>");
  Serial.println("");
  Serial.println("Joint Limits:");
  Serial.println(
      "  JLIM <id|*> <min> <max> : Set logical joint limits (degrees)");
  Serial.println(
      "  Example: JLIM 1 -90 90  : Joint 1 can only go -90 to +90 degrees");
  Serial.println("");
  Serial.println("Gear Ratio:");
  Serial.println("  GEAR <id> <ratio> : Set external gear ratio");
  Serial.println("");
  Serial.println("");
  Serial.println("Absolute Encoders:");
  Serial.println(
      "  ENCSHOW             : Show encoder mappings & raw readings");
  Serial.println(
      "  ENCMAP <enc> <motor> : Map encoder index to motor ID (0=unmap)");
  Serial.println(
      "  ABSPID <id|*> <0|1>  : Use mapped abs encoder for PID (safe sync)");
  Serial.println("  HOPEN [0-255]       : Open hand with PWM (default 255)");
  Serial.println("  HCLOSE [0-255]      : Close hand with PWM (default 255)");
  Serial.println("  HSTOP               : Stop hand PWM");
  Serial.println("  HAND <-255..255>    : Signed hand PWM (+open, -close)");
  Serial.println("  ENCZERO <enc>       : Set encoder zero point");
  Serial.println("  ENCREV <enc>        : Toggle encoder direction");
  Serial.println("  ENCREVSET <enc> <0|1> [motor] : Set encoder direction "
                 "(0=normal, 1=reversed)");
  Serial.println("  BLINK               : Blink onboard LED for 5 seconds");
  Serial.println("");
  Serial.println("S : Stop ALL motors");
  Serial.println("H : Help ASK ZAC FOR HELP");
}

void handleSerial() {
  if (!Serial.available())
    return;

  String line = Serial.readStringUntil('\n');
  line.trim();
  if (line.length() == 0)
    return;
  line.toUpperCase();

  // --- Semicolon batch: split by ';' and process each sub-command ---
  int start = 0;
  while (true) {
    int sep = line.indexOf(';', start);
    String sub =
        (sep == -1) ? line.substring(start) : line.substring(start, sep);
    sub.trim();
    if (sub.length() > 0)
      processCommand(sub);
    if (sep == -1)
      break;
    start = sep + 1;
  }
}

// Resolves a motor ID string: returns -1 for wildcard *, else the 1-based int
// Sets isWildcard true when * is used
static float wrap360f(float angle) {
  while (angle >= 360.0f)
    angle -= 360.0f;
  while (angle < 0.0f)
    angle += 360.0f;
  return angle;
}

static float clampf(float v, float lo, float hi) {
  if (v < lo)
    return lo;
  if (v > hi)
    return hi;
  return v;
}

// Return the wrapped equivalent of angleDeg that is closest to referenceDeg.
static float nearestEquivalent(float angleDeg, float referenceDeg) {
  float turns = roundf((referenceDeg - angleDeg) / 360.0f);
  return angleDeg + (turns * 360.0f);
}

static float getControlTotalAngle(uint8_t motorIndex) {
  if (motorIndex >= MOTOR_NUM)
    return 0.0f;
  if (motor[motorIndex].hasAbsEncoder &&
      motor[motorIndex].useAbsEncoderForPID) {
    return motor[motorIndex].absEncoderTotalAngle;
  }
  return motor[motorIndex].totalAngle;
}

static float getControlLogicalAngle(uint8_t motorIndex) {
  if (motorIndex >= MOTOR_NUM)
    return 0.0f;
  return getControlTotalAngle(motorIndex) - zeroAtControlTotal[motorIndex];
}

static bool isJointFullRange(uint8_t motorIndex) {
  if (motorIndex >= MOTOR_NUM)
    return true;
  return (jointMax[motorIndex] - jointMin[motorIndex]) >= 359.5f;
}

static int8_t findMappedEncoderForMotor(uint8_t motorIndex) {
  if (motorIndex >= MOTOR_NUM)
    return -1;
  for (uint8_t e = 0; e < NUM_ENCODERS; e++) {
    if (absEncoderMotorMap[e] == (int8_t)motorIndex)
      return (int8_t)e;
  }
  return -1;
}

static float projectLogicalTargetToLimits(uint8_t motorIndex, float targetDeg,
                                          float referenceDeg) {
  if (motorIndex >= MOTOR_NUM)
    return targetDeg;
  if (isJointFullRange(motorIndex)) {
    return nearestEquivalent(targetDeg, referenceDeg);
  }
  referenceDeg =
      clampf(referenceDeg, jointMin[motorIndex], jointMax[motorIndex]);
  if (targetDeg >= jointMin[motorIndex] && targetDeg <= jointMax[motorIndex]) {
    return targetDeg;
  }
  return clampf(nearestEquivalent(targetDeg, referenceDeg),
                jointMin[motorIndex], jointMax[motorIndex]);
}

static void clampActiveAngleTargetToLimits(uint8_t motorIndex) {
  if (motorIndex >= MOTOR_NUM || motor[motorIndex].mode != MODE::ANGLE)
    return;
  if (isJointFullRange(motorIndex))
    return;

  float currentLogical = getControlLogicalAngle(motorIndex);
  float targetLogical =
      motor[motorIndex].target.angle - zeroAtControlTotal[motorIndex];
  float clampedLogical =
      projectLogicalTargetToLimits(motorIndex, targetLogical, currentLogical);
  motor[motorIndex].target.angle =
      zeroAtControlTotal[motorIndex] + clampedLogical;
  motor[motorIndex].anglePid.integral = 0.0f;
  motor[motorIndex].anglePid.prevError = 0.0f;
}

static void fallbackMotorToInternalEncoder(uint8_t motorIndex) {
  if (motorIndex >= MOTOR_NUM)
    return;
  float previousLogical = getControlLogicalAngle(motorIndex);
  float previousTargetLogical =
      motor[motorIndex].target.angle - zeroAtControlTotal[motorIndex];
  zeroAtControlTotal[motorIndex] =
      motor[motorIndex].totalAngle - previousLogical;
  motor[motorIndex].useAbsEncoderForPID = false;
  if (motor[motorIndex].mode == MODE::ANGLE) {
    motor[motorIndex].target.angle =
        zeroAtControlTotal[motorIndex] + previousTargetLogical;
    clampActiveAngleTargetToLimits(motorIndex);
  }
  motor[motorIndex].anglePid.integral = 0.0f;
  motor[motorIndex].anglePid.prevError = 0.0f;
}

static void resetAbsStateForMotor(uint8_t motorIndex) {
  if (motorIndex >= MOTOR_NUM)
    return;
  motor[motorIndex].absEncoderAngle = 0.0f;
  motor[motorIndex].absEncoderTotalAngle = 0.0f;
  motor[motorIndex].absEncoderLastRaw = 0;
  motor[motorIndex].absEncoderRoundCount = 0;
  motor[motorIndex].hasAbsEncoder = false;
  motor[motorIndex].useAbsEncoderForPID = false;
}

void setHandPwm(int pwmCommand) {
  if (pwmCommand > 255)
    pwmCommand = 255;
  if (pwmCommand < -255)
    pwmCommand = -255;
  handPwmCommand = pwmCommand;
  if (pwmCommand > 0) {
    digitalWrite(HAND_DIR_PIN, HIGH);
    analogWrite(HAND_PWM_PIN, pwmCommand);
  } else if (pwmCommand < 0) {
    digitalWrite(HAND_DIR_PIN, LOW);
    analogWrite(HAND_PWM_PIN, -pwmCommand);
  } else {
    analogWrite(HAND_PWM_PIN, 0);
  }
}

void startBlinkLed() {
  blinkActiveUntilMs = millis() + 5000;
  blinkLastToggleMs = 0;
  blinkLedState = false;
  digitalWrite(LED_BUILTIN, LOW);
}

static void dispatchMotorIDs(String idStr, bool &isWildcard, int &singleId) {
  if (idStr == "*") {
    isWildcard = true;
    singleId = -1;
  } else {
    isWildcard = false;
    singleId = idStr.toInt();
  }
}
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

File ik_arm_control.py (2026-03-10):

import numpy as np
import math
import matplotlib.pyplot as plt
from matplotlib.widgets import Slider, Button, CheckButtons
import serial
import serial.tools.list_ports
import time
import threading
import sys
import traceback
import tempfile
import os
import json
import re
import queue

CONFIG_FILE = "robot_config.json"
robot_config = {}
wrist_diff_config = {}
controller_config = {}

try:
    from ikpy.chain import Chain
except ImportError:
    print("Error: ikpy or its dependencies not found.")
    print("Please install requirements by running:")
    print("pip install ikpy pyserial matplotlib numpy scipy")
    sys.exit(1)

try:
    from pynput import keyboard
except ImportError:
    print("Error: pynput library not found.")
    print("Please install it running: pip install pynput")
    sys.exit(1)

# --- Configuration ---
BAUD_RATE = 115200
URDF_FILE = "URDF/URDF.urdf"

# Disable default matplotlib key bindings to prevent interference with WASD Controls
for key in list(plt.rcParams.keys()):
    if key.startswith('keymap.'):
        plt.rcParams[key] = []

# --- Globals ---
ser = None
read_thread = None
tx_thread = None
wrist_diff_thread = None
serial_running = True
cmd_queue = queue.Queue()
controller_ports = {"base": None, "joint4": None, "wrist": None}
controller_serial = {"base": None, "joint4": None, "wrist": None}
controller_read_threads = {"base": None, "joint4": None, "wrist": None}
controller_tx_threads = {"base": None, "joint4": None, "wrist": None}
controller_cmd_queues = {"base": queue.Queue(), "joint4": queue.Queue(), "wrist": queue.Queue()}
controller_last_telemetry_line = {"base": "", "joint4": "", "wrist": ""}
expected_controller_names = set()
my_chain = None
current_target_xyz = [0.2, 0.0, 0.3]  # Default safe position
current_target_rpy = [0.0, 0.0, 0.0]  # Roll, Pitch, Yaw
current_joint_angles = [0.0]*6
actual_joint_angles = None
is_previewing = False
preview_start_time = 0
PREVIEW_DURATION = 2.5 # seconds for preview animation
live_update = False
sync_model_to_telemetry = True
last_send_time = 0

PLANAR_MODE = True
PLANAR_ACTIVE_MOTORS = {2, 3}
LOCKED_MOTORS = {1, 4, 5, 6}
LOCKED_BOUNDS_EPS_RAD = 1e-4
DEFAULT_IK_ZERO_OFFSETS = {3: -90.0}
locked_joint_rads = {mid: 0.0 for mid in range(1, 7)}
planar_target_y = 0.0

cam_elev = 20.0
cam_azim = -60.0
DISPLAY_MIRROR_X = True
arm_line = None
ghost_line = None
target_point = None
joint_texts = []
arm_line_top = None
ghost_line_top = None
target_point_top = None
arm_line_side = None
ghost_line_side = None
target_point_side = None
ax_top = None
ax_side = None

txt_joint_dashboard = None
btn_connection = None
txt_connection_status = None

# --- Safety Controls ---
FULL_RANGE_EPS = 359.5
MAX_COMMAND_STEP_DEG = 6.0
MAX_COMMAND_RATE_DEG_PER_SEC = 120.0
COMMAND_DEADBAND_DEG = 0.20
RAMP_INTERVAL_SEC = 0.03
RECENT_COMMAND_HOLD_SEC = 0.35

last_sent_logical_deg = {i: None for i in range(1, 7)}
latest_motor_pos_deg = {}
latest_motor_apos_deg = {}
latest_motor_telemetry_time = {}
last_command_wall_time = 0.0
last_serial_command = ""
last_serial_command_time = 0.0
serial_command_count = 0
last_telemetry_line = ""
wrist_diff_target_logical_deg = {"pitch": None, "roll": None}
wrist_diff_pid_state = {
    "pitch": {"integral": 0.0, "prev_error": 0.0},
    "roll": {"integral": 0.0, "prev_error": 0.0},
}
wrist_diff_last_update_time = 0.0
wrist_diff_last_motor_cmd = (None, None)
hand_pwm_command = 0
abspid_skip_state = {}

TELEMETRY_STALE_SEC = 1.0
AUTO_MOVE_TO_ZERO_ON_CONNECT = True
AUTO_MOVE_TO_ZERO_WAIT_SEC = 1.5
CONTROLLER_MOTOR_GROUPS = {
    "base": {1, 2, 3},
    "joint4": {4},
    "wrist": {5, 6},
}
BROADCAST_COMMANDS = {"S", "TON", "TOFF", "T"}


def _safe_float(v):
    try:
        return float(v)
    except Exception:
        return None


def _get_zero_offset(mid):
    try:
        return float(robot_config.get(str(mid), {}).get("zero_offset", 0.0))
    except Exception:
        return 0.0


def _get_controller_defaults():
    return {
        "base": {"port": None, "motors": [1, 2, 3]},
        "joint4": {"port": None, "motors": [4]},
        "wrist": {"port": None, "motors": [5, 6]},
    }


def _normalize_controller_config(raw_cfg):
    merged = _get_controller_defaults()
    if not isinstance(raw_cfg, dict):
        return merged
    for name in ("base", "joint4", "wrist"):
        cfg = raw_cfg.get(name, {}) if isinstance(raw_cfg.get(name, {}), dict) else {}
        if cfg.get("port") not in (None, ""):
            merged[name]["port"] = str(cfg.get("port"))
        motors = cfg.get("motors")
        if isinstance(motors, list):
            out = []
            for mid in motors:
                try:
                    out.append(int(mid))
                except Exception:
                    pass
            if out:
                merged[name]["motors"] = out
    return merged


def _controller_for_motor(mid):
    try:
        motor_id = int(mid)
    except Exception:
        return "base"
    active_groups = CONTROLLER_MOTOR_GROUPS
    if controller_config:
        active_groups = {
            name: set(cfg.get("motors", []))
            for name, cfg in controller_config.items()
        }
    for controller_name, motor_ids in active_groups.items():
        if motor_id in motor_ids:
            return controller_name
    return "base"


def _controller_owns_motor(controller_name, motor_id):
    cfg = controller_config.get(controller_name, {}) if isinstance(controller_config.get(controller_name, {}), dict) else {}
    assigned = cfg.get("motors", []) if isinstance(cfg.get("motors", []), list) else []
    if not assigned:
        return True
    assigned_ids = set()
    for mid in assigned:
        try:
            assigned_ids.add(int(mid))
        except Exception:
            pass
    if not assigned_ids:
        return True
    try:
        return int(motor_id) in assigned_ids
    except Exception:
        return False


def _connected_controller_names():
    return [name for name, conn in controller_serial.items() if conn and conn.is_open]


def _required_controller_names():
    if expected_controller_names:
        return set(expected_controller_names)
    return set(_connected_controller_names())
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

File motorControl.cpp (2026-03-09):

#include "motorControl.h"
#include <cmath>
#include <cstring>

motorControl::motorControl()
    : motors(nullptr), motorCount(0), pidIntervals(nullptr), lastUpdateTime(0) {
}

void motorControl::setMotor(motor_t *motorArray, uint8_t count) {
  motors = motorArray;
  motorCount = count;
}

void motorControl::setPidInterval(pidInterval_t *intervals) {
  pidIntervals = intervals;
}

void motorControl::init() {
  lastUpdateTime = micros();
  for (uint8_t i = 0; i < motorCount; i++) {
    motors[i].lastRawAngle = 0;
    motors[i].roundCount = 0;
    motors[i].totalAngle = 0;
    motors[i].speedPid.prevError = 0;
    motors[i].speedPid.integral = 0;
    motors[i].anglePid.prevError = 0;
    motors[i].anglePid.integral = 0;
    // Absolute encoder fields (populated externally by goo.ino)
    motors[i].hasAbsEncoder = false;
    motors[i].useAbsEncoderForPID = false;
    motors[i].absEncoderAngle = 0.0f;
    motors[i].absEncoderTotalAngle = 0.0f;
    motors[i].absEncoderLastRaw = 0;
    motors[i].absEncoderRoundCount = 0;
  }
}

float motorControl::calculatePID(pid_params_t *pid, float error, float dt) {
  float pOut = pid->kp * error;
  pid->integral += pid->ki * error * dt;
  if (pid->integral > pid->integralLimit)
    pid->integral = pid->integralLimit;
  if (pid->integral < -pid->integralLimit)
    pid->integral = -pid->integralLimit;
  float derivative = (error - pid->prevError) / dt;
  pid->prevError = error;
  float output = pOut + pid->integral + (pid->kd * derivative);
  if (output > pid->outputLimit)
    output = pid->outputLimit;
  if (output < -pid->outputLimit)
    output = -pid->outputLimit;
  return output;
}

void motorControl::parseMotorFeedback(struct can_frame *readMsg) {
  uint8_t motorId = readMsg->can_id - 0x201;
  if (motorId >= motorCount)
    return;

  uint16_t rawAngle = (readMsg->data[0] << 8) | readMsg->data[1];
  int16_t rawSpeed = (readMsg->data[2] << 8) | readMsg->data[3];
  int16_t rawCurrent = (readMsg->data[4] << 8) | readMsg->data[5];
  motors[motorId].temperature = readMsg->data[6];

  // Calculate total gear ratio (motor internal * external gearing)
  float totalGearRatio =
      motors[motorId].gearRatio * motors[motorId].externalGearRatio;

  // RPM needs to be divided by total gear ratio to get final Output RPM
  motors[motorId].actualSpeed = (float)rawSpeed / totalGearRatio;
  motors[motorId].actualCurrent = (float)rawCurrent / 1000.0;

  // Angle Unwrapping
  int32_t diff = rawAngle - motors[motorId].lastRawAngle;
  if (diff < -4096)
    motors[motorId].roundCount++;
  else if (diff > 4096)
    motors[motorId].roundCount--;
  motors[motorId].lastRawAngle = rawAngle;

  // Calculate Total Rotor Angle
  float rotorAngle = (motors[motorId].roundCount * 360.0f) +
                     ((float)rawAngle * 360.0f / 8192.0f);

  // *** CRITICAL: Divide by Total Gear Ratio ***
  // Now 'totalAngle' represents the FINAL OUTPUT SHAFT angle
  motors[motorId].totalAngle = rotorAngle / totalGearRatio;

  // Also update actualAngle for single-revolution display (0-360)
  motors[motorId].actualAngle = (float)rawAngle * 360.0f / 8192.0f;
}

void motorControl::updateMotorCommand(struct can_frame *sendMsg,
                                      uint8_t motorIndex, float dt) {
  if (motorIndex >= motorCount)
    return;

  float currentCmd = 0.0f;
  motor_t *m = &motors[motorIndex];

  if (m->mode == MODE::SPEED) {
    // Hard idle at zero target: do not run speed PID on noisy feedback.
    if (fabsf(m->target.speed) < 0.5f) {
      currentCmd = 0.0f;
      m->speedPid.integral = 0.0f;
      m->speedPid.prevError = 0.0f;
    } else {
      float error = m->target.speed - m->actualSpeed;
      currentCmd = calculatePID(&m->speedPid, error, dt);
    }
  } else if (m->mode == MODE::ANGLE) {
    // Simplified single-loop position control:
    // Position PID output is mapped directly to current command (A).
    // Speed PID is bypassed entirely in ANGLE mode.
    float currentAngle = (m->hasAbsEncoder && m->useAbsEncoderForPID)
                             ? m->absEncoderTotalAngle
                             : m->totalAngle;
    float posError = m->target.angle - currentAngle;
    float pOut = m->anglePid.kp * posError;
    m->anglePid.integral += m->anglePid.ki * posError * dt;
    if (m->anglePid.integral > m->anglePid.integralLimit)
      m->anglePid.integral = m->anglePid.integralLimit;
    if (m->anglePid.integral < -m->anglePid.integralLimit)
      m->anglePid.integral = -m->anglePid.integralLimit;
    float derivative = (posError - m->anglePid.prevError) / dt;
    m->anglePid.prevError = posError;
    float posOut = pOut + m->anglePid.integral + (m->anglePid.kd * derivative);

    // Legacy compatibility: angle PID output was historically RPM-like.
    // Convert to current with a fixed gain for direct drive.
    // Keep this direct but not too aggressive.
    const float kPosOutToCurrent = 0.02f; // 100 units -> 2 A
    currentCmd = posOut * kPosOutToCurrent;

    float maxCurrent = m->speedPid.outputLimit;
    if (maxCurrent > 0.0f) {
      if (currentCmd > maxCurrent)
        currentCmd = maxCurrent;
      if (currentCmd < -maxCurrent)
        currentCmd = -maxCurrent;
    }

    float maxSpeed = m->anglePid.outputLimit;
    if (maxSpeed > 0.0f && fabsf(m->actualSpeed) >= maxSpeed) {
      if ((m->actualSpeed > 0.0f && currentCmd > 0.0f) ||
          (m->actualSpeed < 0.0f && currentCmd < 0.0f)) {
        currentCmd = 0.0f;
      }
    }

    // Near target, bleed integrator and hard-idle to suppress periodic twitches.
    if (fabsf(posError) < 0.20f) {
      m->anglePid.integral *= 0.8f;
      if (fabsf(m->anglePid.integral) < 0.02f)
        m->anglePid.integral = 0.0f;
      currentCmd = 0.0f;
    }

    // Wider deadband to suppress micro-chatter on encoder noise.
    if (fabsf(currentCmd) < 0.10f && fabsf(posError) < 0.40f) {
      currentCmd = 0.0f;
    }
  } else if (m->mode == MODE::CURRENT) {
    // Direct current command (open-loop bypass of speed PID)
    currentCmd = m->target.current;
  }

  if (m->direction == DIRECTION::REV)
    currentCmd = -currentCmd;

  // Current (Amps) to C620 value (-16384 to 16384)
  // C620 max current is 20A, mapped to 16384
  int16_t sendVal = (int16_t)(currentCmd * (16384.0f / 20.0f));

  if (sendVal > 16384)
    sendVal = 16384;
  if (sendVal < -16384)
    sendVal = -16384;

  uint8_t frameIndex = (m->id - 1) / 4;
  uint8_t offset = (m->id - 1) % 4;
  sendMsg[frameIndex].data[offset * 2] = (sendVal >> 8) & 0xFF;
  sendMsg[frameIndex].data[offset * 2 + 1] = sendVal & 0xFF;
}
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

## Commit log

2026-02-08 Initial commit of RoboMaster Motor Control Project
2026-02-08 Docs: Added common ground instruction
2026-02-21 Add Python control scripts and Cytron MD10C driver support
2026-02-21 chore: remove all homing logic and documentation
2026-02-25 Add PID tuner GUI, high-refresh IK arm control visualization, and configuration management
    [J1to2_v111.stl, J2to3_v211.stl, J3to4_v111.stl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]
2026-03-03 Joint limits, CAL zero, jog controls, PID fixes, serial log, gauge vis
    [cytron_control.py, differential_wrist_control.py, encoder_test.ino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]
2026-03-09 AI update
    [URDF.urdf, diff2.txt, motor_diff.txt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]
2026-03-09 ik bug fixes, support for multi xiaos on one pc, added ability to regain prior position after power loss
    [wrist_visualization.urdf]
2026-03-14 Add multi-motor keyboard controller with keymap and docs
    [multi_motor_keymap.json]
2026-04-22 Fix CS pin conflict (remove D3 from ENC_CS_PINS)
    [goo.ino]
